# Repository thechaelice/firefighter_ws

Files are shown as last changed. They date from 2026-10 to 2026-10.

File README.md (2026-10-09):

# Autonomous Firefighter Robot (`firefighter_ws`)

An autonomous firefighting robotic system designed for rapid fire detection, navigation, localization, and suppression. The system integrates low-power wireless alert beacons with an autonomous mobile robot equipped with LiDAR SLAM, laser odometry, thermal vision, and a targeted fire retardant delivery system.

---

## Architecture Overview

```mermaid
flowchart TD
    subgraph Beacon [Fire Beacon - ESP32]
        B1[Fire / Smoke Sensor] --> B2[ESP32 Controller]
        B2 -->|ESP-NOW Wireless Alert| R2
    end

    subgraph Robot [Mobile Firefighter Robot]
        subgraph ESP32_Robot [Mobility Controller - ESP32]
            R2[ESP-NOW Receiver] --> R3[Motor Drivers & Locomotion]
        end

        subgraph Pi_Robot [Processing & Perception - Raspberry Pi]
            Lidar[RPLiDAR Sensor] -->|Serial| ROS_Scan[ROS 2: sllidar_ros2]
            ROS_Scan -->|/scan| ROS_Odom[ROS 2: rf2o_laser_odometry]
            ROS_Odom -->|/odom_rf2o + TF| SLAM[SLAM & Navigation Stack]
            Thermal[Thermal Camera - MLX90641 16x12] --> ML[Flame Localization & ML - In development]
            Extinguisher[Fire Retardant Dispenser - Planned]
        end

        Pi_Robot <-->|UART / ROS-Serial| ESP32_Robot
    end
```

### 1. Smart Fire Beacon (ESP32)
* **Function**: Acts as a remote smoke / heat detector placed in monitored rooms.
* **Communication**: Transmits low-latency, low-power alert signals to the robot over **ESP-NOW** when fire or smoke is detected.

### 2. Autonomous Mobile Robot
The robot is built with a dual-controller architecture:
* **Raspberry Pi (High-Level Computing & Perception)**:
  * Runs ROS 2 (Jazzy) for sensor processing, LiDAR SLAM, mapping, path planning, and ML workloads.
  * Interfaces with the LiDAR for real-time laser odometry and 2D environmental mapping.
  * Thermal imaging with a **Melexis MLX90641** (16 × 12 = 192-pixel) IR array on
    I²C (`0x33`) to pinpoint the base of the flame — driver verified, perception in
    development (see [`docs/thermal-camera.md`](docs/thermal-camera.md)).
* **ESP32 (Mobility & Hardware Control)**:
  * Handles low-level motor drivers, wheel velocity control, and wheel odometry.
  * Maintains the ESP-NOW communication link with fire alert beacons.

---

## System Operational Workflow

1. **Detection & Alert**: An ESP32 beacon senses smoke/fire and dispatches a beacon alert packet via ESP-NOW.
2. **Dispatch & Navigation**: The robot receives the alert and uses LiDAR-based SLAM and odometry (`rf2o_laser_odometry`) to navigate autonomously to the reported room.
3. **Flame Localization**: Once in proximity, the onboard **MLX90641** thermal camera (16 × 12 IR array) scans the area to pinpoint the exact fire source.
4. **Fire Suppression**: The robot positions itself and activates the fire retardant dispensing mechanism to extinguish the flames.

---

## Current Repository Status

| Component | Hardware / Software | Status | Description |
|---|---|---|---|
| **LiDAR Driver** | RPLiDAR + `sllidar_ros2` | ✅ Implemented | Reads LiDAR data and publishes `/scan` topic |
| **Laser Odometry** | `rf2o_laser_odometry` | ✅ Implemented | Computes planar odometry (`/odom_rf2o`, `odom → base_link` TF) |
| **Live LiDAR Terminal Viewer** | `scripts/ascii_lidar_view.py` | ✅ Implemented | Headless polar ASCII radar visualizer for `/scan` |
| **Operations Dashboard** | `scripts/robot_dashboard.py` | ✅ Implemented | One web page: LiDAR 2D/3D, optional SLAM map and thermal camera feeds, beacon alerts + RSSI, ESP32 link/mode/e-stop, mission state, odometry, per-topic rates, event log |
| **Motor Bench Test** | `scripts/motor_test.py` | ✅ Implemented | Drives the motors from the Pi via `/cmd_vel` (scripted or keyboard) with `/wheel_odom` feedback |
| **Thermal Frame Capture/Render** | `scripts/thermal_frames.py` + `scripts/thermal/` | ✅ Implemented | Captures Melexis **MLX90641** frames and renders PNG heat maps (see [`docs/thermal-camera.md`](docs/thermal-camera.md)) |
| **Pi ↔ ESP32 Serial Bridge** | `firefighter_bridge` (ament_python) | ✅ Implemented | Framed UART link: `/cmd_vel` → `SET_TWIST`, wheel odom, beacon events (see [`src/firefighter_bridge/`](src/firefighter_bridge/README.md)) |
| **Mission Behaviour FSM** | `firefighter_mission` (ament_python) | ✅ Implemented | `beacon → navigate → search → suppress → verify` state machine, e-stop, bounded timeouts (see [`src/firefighter_mission/`](src/firefighter_mission/README.md)) |
| **ESP-NOW Fire Beacon** | ESP32 + Flame/Smoke Sensors | ✅ Implemented | HL-01 flame + MQ-2 smoke sensing with detection latching, non-blocking 2 s ESP-NOW alert transmission (see [`firmware/`](firmware/README.md)) |
| **Robot Mobility Controller** | ESP32 + Motor Drivers | ✅ In Firmware | Motor control firmware and ESP-NOW receiver (see [`firmware/`](firmware/README.md)) |
| **SLAM & Path Planning** | `slam_toolbox` + Nav2 + `robot_localization` | ✅ Implemented | Mapping, EKF fusion (`/odom_rf2o` + `/wheel_odom`) and Nav2 path planning (see [`src/firefighter_bringup/`](src/firefighter_bringup/README.md)) |
| **Thermal Flame Localization**| Melexis **MLX90641** (16 × 12) + ML model | ✅ Implemented | 16×12 IR array → thermal image + bearing/range to the flame (see [`src/firefighter_perception/`](src/firefighter_perception/README.md)); ML model still pending |
| **Fire Retardant Dispenser** | Actuator / Pump / Nozzle | ⏳ Planned | Automated fire suppression dispenser |

### Upstream ROS 2 Packages

The following packages are included in `src/`:

* [`sllidar_ros2`](src/sllidar_ros2/) from [Slamtec/sllidar_ros2](https://github.com/Slamtec/sllidar_ros2)
* [`rf2o_laser_odometry`](src/rf2o_laser_odometry/) from [MAPIRlab/rf2o_laser_odometry](https://github.com/MAPIRlab/rf2o_laser_odometry)

---

## Getting Started (ROS 2 Workspace)

### 1. Build the Workspace

Ensure ROS 2 (Jazzy) is installed and sourced. For a from-scratch install - the
Pi, or Gazebo simulation on a PC under WSL2 - follow [`setup.md`](setup.md).

> [!WARNING]
> On this Raspberry Pi 4, do **not** run a bare `colcon build --symlink-install`.
> colcon runs each package as `cmake --build ... -- -j4 -l4` and builds packages
> in parallel, i.e. up to 8 concurrent `g++` jobs on a 4-core board with 3.7 GB
> RAM and **no swap**, while the VS Code remote server is resident. That drives
> the system into memory pressure, whose writeback wedges the SD/MMC controller
> (`mmc_rescan` blocked >120 s). Since the root filesystem *and* the Wi-Fi radio
> both hang off that MMC/SDIO bus, the Pi loses disk I/O and networking at the
> same time — SSH drops and can't reconnect, and only a power cycle recovers it.

Use the wrapper instead, which caps compiler parallelism and builds one package
at a time:

```bash
cd ~/firefighter_ws
./build.sh
```

Equivalent to running the following by hand:

```bash
cd ~/firefighter_ws
source /opt/ros/jazzy/setup.bash
MAKEFLAGS="-j1 -l1" colcon build --symlink-install --executor sequential
source install/setup.bash
```

`install/setup.bash` only appears once a build finishes successfully — if
`sourcing install/setup.bash` fails, the previous build did not complete.

#### Recommended Pi hardening (prevents the lockups entirely)

The build wrapper avoids *triggering* the fault; these steps make the board
robust if it happens for another reason:

```bash
# 1. zram swap: compressed swap in RAM, so memory pressure never turns into
#    SD-card writeback. Cheap and safe on a Pi.
sudo apt install zram-tools
#    then set ALGO=zstd and PERCENT=50 in /etc/default/zramswap and
#    sudo systemctl restart zramswap

# 2. earlyoom: kills the biggest memory hog before the box wedges, instead of
#    hanging until the MMC controller gives up.
sudo apt install earlyoom
```

Also worth doing:

- **Put the root filesystem on a USB SSD** (or at least a better SD card). This
  unit's card reports as a generic `SD32G` in DDR50 mode, and cheap cards stall
  under sustained writeback — the actual trigger here.
- **Disable Wi-Fi power save** (`iw dev wlan0 set power_save off`, or the
  NetworkManager `wifi.powersave 2` setting) or, better, **use Ethernet**. SSH
  currently runs over a Wi-Fi hotspot, and the radio shares the MMC/SDIO bus
  with the SD card, so a storage stall also kills the network link.

---

### 2. Launch the LiDAR Driver

```bash
ros2 launch sllidar_ros2 sllidar_a1_launch.py serial_port:=/dev/ttyUSB0
```

### 3. Launch Laser Odometry

```bash
ros2 launch rf2o_laser_odometry rf2o_laser_odometry.launch.py
```

### 4. Optional: Terminal ASCII LiDAR Visualizer

For headless debugging over SSH:

```bash
python3 scripts/ascii_lidar_view.py
```

### 5. Optional: Operations Dashboard (browser)

`scripts/robot_dashboard.py` serves a single page with everything the robot is
doing: the live LiDAR scan (2D and optional 3D), beacon alerts with RSSI and an
estimated range, the mobility ESP32's link/mode/e-stop state, the mission FSM
state and suppression, wheel vs laser odometry, a per-topic rate and freshness
table, and a rolling event log.

```bash
cd ~/firefighter_ws && source install/setup.bash
python3 scripts/robot_dashboard.py
```

Open `http://<pi-ip>:8080/` from a browser on the same network. The 3D view can
display a `PointCloud2` topic when configured:

```bash
python3 scripts/robot_dashboard.py --pointcloud-topic /points
```

The RPLIDAR publishes planar `LaserScan` data, so without a `PointCloud2` topic
the 3D view shows the scan as a flat plane. The server has no authentication and
binds to all interfaces; use it only on a trusted network.

### 6. Optional: Drive the Motors (bench test)

`scripts/motor_test.py` is a bring-up tool for the drive train. It publishes
`/cmd_vel`, which `firefighter_bridge` streams to the ESP32 as `SET_TWIST`, and
reports `/wheel_odom` back so you can see the wheels turning.

```bash
cd ~/firefighter_ws && source install/setup.bash

# creep forward for 2 s, then stop
python3 scripts/motor_test.py --linear 0.10 --duration 2

# spin in place
python3 scripts/motor_test.py --angular 0.5 --duration 3

# keyboard driving: w/s = speed, a/d = turn, space = stop, q = quit
python3 scripts/motor_test.py --interactive
```

> **Stop `firefighter_mission` first.** It also publishes `/cmd_vel`, so the two
> will fight over the motors.

Put the robot on blocks for the first run. Zero is published on every exit path,
and killing the script stops the robot anyway (the bridge zeros stale commands
after `cmd_timeout_s`, and the ESP32 stops itself after `PI_TIMEOUT_MS`).
Add `--estop` to latch a stop on the ESP32 when the test finishes.

For detailed setup, troubleshooting, and port configuration, refer to [`docs/runbook.md`](docs/runbook.md).

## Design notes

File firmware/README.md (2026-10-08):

# ESP32 Firmware Documentation

This directory contains the embedded firmware for the Firefighter Robot system, split into two ESP32 microcontrollers communicating wirelessly via **ESP-NOW**.

---

## Directory Layout

```text
firmware/
├── beacon/
│   └── beacon.ino             # Fire & smoke detector beacon sketch (Sender)
├── robot_mobility/
│   └── robot_mobility.ino     # Robot motor driver & ESP-NOW receiver sketch
└── README.md                  # Firmware guide, pinouts, and flashing instructions
```

---

## System Architecture

```mermaid
flowchart LR
    subgraph Beacon [Fire Beacon - ESP32]
        Sensor[Flame / Smoke Sensor] --> BeaconESP[ESP32 Sender]
        BeaconESP -->|ESP-NOW Broadcast / Unicast| RecvESP
    end

    subgraph Robot [Robot Mobility - ESP32]
        RecvESP[ESP32 Receiver] --> Drivers[L298N / Motor Driver]
        Drivers --> M1[Motor 1 (Left)]
        Drivers --> M2[Motor 2 (Right)]
        Encoders[Quadrature Encoders] -.-> RecvESP
    end
```

---

## 1. Wireless Protocol (ESP-NOW)

The beacon and the robot communicate using **ESP-NOW**, a low-latency, low-power peer-to-peer 2.4 GHz wireless protocol developed by Espressif.

### Packet Structure
Both sender (`beacon.ino`) and receiver (`robot_mobility.ino`) must share the exact same message struct:

```cpp
typedef struct struct_message {
    int messageNumber;
    bool fireDetected;
    bool smokeDetected;
} struct_message;
```

### Pairing & MAC Address Setup
Pairing is automatic; no MAC address is hardcoded.

1. The beacon broadcasts a `PAIR_REQUEST` every 500 ms until it has a receiver.
2. The mobility ESP32 answers with a broadcast `PAIR_REPLY`.
3. The beacon takes the receiver MAC from the source address of that reply, registers it as its ESP-NOW peer and starts sending alert packets to it (`Receiver found: XX:XX:XX:XX:XX:XX` on the beacon's Serial Monitor).
4. After 5 consecutive undelivered packets the beacon forgets the receiver and goes back to step 1, so a swapped or rebooted mobility ESP32 is picked up without reflashing.

Both sketches must be flashed with matching `pair_message` definitions. The beacon pairs with the first mobility ESP32 that answers, so only one should be powered within range.

### Signal Strength (RSSI) & Distance Estimation
* **Interim (Active)**: The mobility ESP32 captures the received packet signal strength (RSSI in dBm) via a promiscuous Wi-Fi hook (Core 2.0.x) or `esp_now_recv_info_t` (Core 3.0.x) and forwards it in `MSG_BEACON_EVENT` to ROS 2 topic `/beacon_event`.
  * Typical indoor Wi-Fi path-loss formula: $\text{RSSI} \approx \text{RSSI}_0 - 10 n \log_{10}(d)$.
  * Provides coarse proximity indication (e.g. Strong: $-40\text{ to }-55\text{ dBm} \rightarrow <2\text{m}$, Moderate: $-60\text{ to }-75\text{ dBm} \rightarrow 2\text{--}6\text{m}$, Weak: $<-80\text{ dBm} \rightarrow >6\text{m}$).
* **Target Upgrade (UWB Ranging)**: Ultra-Wideband Two-Way Ranging (DWM1000/DWM3000) for high-precision $\pm 5\text{--}10\text{ cm}$ indoor ranging. See the [UWB Migration Guide](../docs/uwb-ranging-migration.md).

---

## 2. Hardware Pinout & Wiring

### Robot Mobility Controller (`robot_mobility.ino`)

#### Motor Driver (e.g. L298N / Dual H-Bridge)
| Signal | ESP32 GPIO | Description |
|---|---|---|
| **ENA** | GPIO 14 | Motor 1 Speed (PWM Channel 0) |
| **IN1** | GPIO 27 | Motor 1 Direction A |
| **IN2** | GPIO 26 | Motor 1 Direction B |
| **IN3** | GPIO 25 | Motor 2 Direction A |
| **IN4** | GPIO 33 | Motor 2 Direction B |
| **ENB** | GPIO 32 | Motor 2 Speed (PWM Channel 1) |

#### Optical / Magnetic Encoders
| Encoder | Channel A (Green) | Channel B (Blue) | Description |
|---|---|---|---|
| **Motor 1** | GPIO 18 | GPIO 19 | Left wheel quadrature encoder |
| **Motor 2** | GPIO 22 | GPIO 23 | Right wheel quadrature encoder |

#### PWM Configuration
* **Frequency**: 5 kHz
* **Resolution**: 8-bit (values `0` – `255`)
* **Default Speed**: `180` (~71% duty cycle), used only by the fallback maneuver

#### Closed-Loop Wheel Speed Control
In Pi-owned mode each `SET_TWIST` becomes a per-wheel speed target, and a 50 Hz
feedforward + PI loop on the encoder speed drives the PWM, so slow commands
(search spin, flame approach, Nav2 fine positioning) are actually achieved.

* **Geometry**: `WHEEL_RADIUS_M` and `ENCODER_TICKS_PER_REV` in the sketch must match `wheel_radius_m` / `ticks_per_rev` in the bridge's `config/bridge.yaml`.
* **Encoder direction**: each encoder must count **up** when its wheel drives the robot forward; flip `M1_ENC_INVERT` / `M2_ENC_INVERT` if not.
* **Encoder fault**: if a wheel's encoder counts opposite to its motor, or gives no counts while driven hard, for 0.7 s, both wheels drop back to open-loop feedforward until `MSG_RESET_FAULT`. It is reported to the Pi as `FLAG_ENC_FAULT` (bit 4) in `MSG_STATUS`, which the bridge raises as an ERROR on `/diagnostics`, and printed as `[vel] ENCODER FAULT` on the debug serial.
* **Tuning**: `VEL_KP`, `VEL_KI` and `MOTOR_MIN_MOVE_PWM` are untuned starting values. `VELOCITY_CONTROL_ENABLED 0` restores open-loop.
* A zero target stops the motors immediately; the loop never reverses a motor to brake.

---

## 3. Behavior & Trigger Logic

> **Note:** the legacy trigger/maneuver described here now runs **only as a fallback**
> (`MOTION_OWNER_IS_PI 0`). By default the Pi owns motion — see [§5](#5-pi--esp32-uart-link-option-a--active).

### Trigger Condition
* The robot requires **2 consecutive packets** with both `fireDetected == true` and `smokeDetected == true` before triggering movement to prevent false positives.
* If a packet arrives without both conditions satisfied, the consecutive counter resets to 0.

### Maneuver Sequence
When triggered, the robot executes the following fixed sequence:
1. **Forward**: 5 seconds
2. **Stop**: 0.5 seconds
3. **Turn Right**: 3 seconds
4. **Stop**: 0.5 seconds
5. **Turn Left**: 5 seconds
6. **Final Stop**: Shuts down motors, clears old flags, and resumes listening for new alert packets.

*Note: During execution of the sequence, all incoming ESP-NOW commands are safely ignored.*

---

## 4. Flashing & Setup Instructions

### Prerequisites
* **Arduino IDE** (v1.8.x or v2.x) or **VS Code with PlatformIO / Arduino extension**
* **ESP32 Board Package**: `esp32` by Espressif Systems (Core 2.0.x recommended)

### Board Settings in Arduino IDE
* **Board**: `ESP32 Dev Module` (or your specific ESP32 board)
* **CPU Frequency**: `240MHz (WiFi/BT)`
* **Flash Frequency**: `80MHz`
* **Upload Speed**: `921600` (or `115200` if flashing fails)
* **Baud Rate**: `115200`

---

## 5. Pi ↔ ESP32 UART Link (Option A — active)

The mobility ESP32 is now a **gateway**: it keeps the ESP-NOW link to the beacon and
bridges everything to the Raspberry Pi over a framed binary UART protocol.

```
Beacon --ESP-NOW--> [Mobility ESP32] --UART2--> Raspberry Pi (ROS 2)
```

### Wiring
| Pi | ESP32 | Note |
|---|---|---|
| GPIO14 (TXD) | GPIO16 (RX) | UART2, 115200 8N1 |
| GPIO15 (RXD) | GPIO17 (TX) | do **not** use UART1 (GPIO9/10 — flash pins) |
| GND | GND | required |

Both sides are 3.3 V — no level shifter. The Pi must expose a UART on GPIO14/15
(see [`docs/runbook.md`](../docs/runbook.md): `dtoverlay=miniuart-bt` and remove the serial console).

### Protocol
Defined once in [`robot_mobility/firefighter_protocol.h`](robot_mobility/firefighter_protocol.h).
Frame: `A5 5A | LEN | MSG_ID | PAYLOAD | CRC16-LE` (CRC-16/CCITT-FALSE over LEN..payload).

| Pi → ESP32 | | ESP32 → Pi | |
|---|---|---|---|
| `SET_TWIST` `0x01` | f32 lin, ang | `WHEEL_ODOM` `0x81` | i32 ticksL/R, u32 dt_us |
| `ESTOP` `0x02` | — | `STATUS` `0x82` | u16 vbat, u8 flags, u8 mode |
| `RESET_FAULT` `0x03` | — | `BEACON_EVENT` `0x83` | u32 msg, fire, smoke, rssi, mac |
| `HEARTBEAT` `0x04` | u16 seq | `ACK` `0x84` / `HB_ESP` `0x85` | |

### Motion ownership
Set by `MOTION_OWNER_IS_PI` at the top of `robot_mobility.ino`:

* **`1` (default)** — the Pi owns motion: it streams `SET_TWIST`, and beacon events are
  only *forwarded* so the Pi's autonomy stack decides what to do.
* **`0`** — fallback: the ESP32 runs its original fixed forward/right/left maneuver on
  two consecutive beacon FIRE + SMOKE detections (still non-blocking).

### Safety
* **Watchdog** — in Pi mode, no valid frame for `PI_TIMEOUT_MS` (500 ms) → motors stop.
* **E-stop** — `ESTOP` latches a stop until `RESET_FAULT` arrives.
* The whole control path is `millis()`-based; the legacy blocking `delay()` maneuver
  is preserved as `robot_mobility.blocking.bak` for reference.

---

## 6. Option B — micro-ROS (deferred)

An alternative where the ESP32 becomes a native ROS 2 node via `micro_ros_agent`,
removing the custom protocol. Kept on the shelf, not built.
See [`docs/option-b-micro-ros.md`](../docs/option-b-micro-ros.md).

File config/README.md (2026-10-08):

# config/

Parameter files for **upstream packages whose source we don't own**. Keeping them
here rather than inside `src/` means a workspace rebuild can never overwrite tuned
values, and `firefighter_bringup` loads them by absolute path.

| File | Package | Status |
|---|---|---|
| `rf2o.yaml` | `rf2o_laser_odometry` | adapted — `publish_tf: false` (the EKF owns `odom → base_link`) |
| `ekf.yaml` | `robot_localization` | purpose-written — fuses `/odom_rf2o` + `/wheel_odom` |
| `slam_toolbox.yaml` | `slam_toolbox` | stock defaults, `base_frame` → `base_link`. **Not tuned** |
| `nav2_params.yaml` | `nav2_bringup` | stock defaults, frames/odom/radius adapted. **Not tuned** |

## Provenance

`slam_toolbox.yaml` and `nav2_params.yaml` are copies of the shipped Jazzy configs:

* `/opt/ros/jazzy/share/slam_toolbox/config/mapper_params_online_async.yaml`
* `/opt/ros/jazzy/share/nav2_bringup/params/nav2_params.yaml`

Only frames, the odometry source and the robot radius were changed; each file has a
header comment listing exactly what differs. **Nothing has been validated on real
hardware** — a stock Nav2 config is a starting point, not a tuned one. Speeds,
acceleration limits, inflation radii and the progress checker all need revisiting
once the robot drives. `robot_radius: 0.18` in particular is a placeholder.

`ekf.yaml` and `rf2o.yaml` were written for this robot rather than copied.

Package-owned parameters live with their package (e.g.
`src/firefighter_bridge/config/bridge.yaml`).

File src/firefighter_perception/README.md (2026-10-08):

# firefighter_perception

Thermal flame perception from the **Melexis MLX90641** 16×12 IR array.

```
MLX90641 (I2C 0x33) ──> scripts/thermal/mlx90641_frames ──> thermal_node ──┬──> /thermal/image       (32FC1)
                              (vendored C reader)                          ├──> /thermal/camera_info
                                                                           └──> /flame_event
                                                                                   ▲
/scan ────────────────────────────────────────────────────────────────────────────┘
```

There is no MLX90641 driver on PyPI (see `docs/thermal-camera.md`), so frames come
from the vendored C tool via `thermal_reader.py`, which runs it in a background
thread and restarts it if it dies. This package needs **no numpy**.

## The array gives a bearing, not a range

A 16×12 array on a fixed-FOV lens tells you *where* the hot spot is, not how far
away it is. Range comes from the LiDAR: `scan_range_at_bearing()` looks up the
`/scan` return at the flame's bearing (median of the returns in a ±6° window, so one
spurious point cannot decide it). That also settles `IN_SUPPRESSION_RANGE`.

## What it publishes, and what it deliberately does not

| State | Meaning |
|---|---|
| `FLAME_FOUND` | a hot spot is present |
| `IN_SUPPRESSION_RANGE` | ...and the LiDAR says it is within `suppression_range_m` |
| `FLAME_LOST` | nothing hot in view |

It never publishes `FLAME_EXTINGUISHED`. Deciding that "gone" means "it went out"
needs to know that you had been suppressing — that is the mission's job, and
`firefighter_mission` maps `FLAME_LOST` → extinguished while suppressing/verifying.

## Topics

| Name | Type | Dir |
|---|---|---|
| `/thermal/image` | `sensor_msgs/Image` (32FC1, degrees C) | out |
| `/thermal/camera_info` | `sensor_msgs/CameraInfo` | out |
| `/flame_event` | `firefighter_interfaces/FlameEvent` | out |
| `/scan` | `sensor_msgs/LaserScan` | in |

## Run

```bash
cd ~/firefighter_ws && ./build.sh && source install/setup.bash
ros2 launch firefighter_perception perception.launch.py
```

`reader_path` defaults to `$FIREFIGHTER_WS/scripts/thermal/mlx90641_frames`
(override with `reader_path:=`). Build the reader first with
`bash scripts/thermal/build.sh`.

## Tuning

`config/perception.yaml`. The thresholds are `min(threshold_c, ambient + delta_c)`,
so a warm room where nothing reaches 60 °C still triggers on a 20 °C rise. Note the
sensor delivers roughly **2 Hz**, not the 5 Hz the acquisition setting suggests —
the MLX90641's subpage reads dominate. Images are published one per *new* frame, not
at the timer rate, so a dead reader cannot keep reporting a stale `FLAME_FOUND`.

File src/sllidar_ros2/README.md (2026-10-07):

# SLAMTEC LIDAR ROS2 Package

ROS2 node for SLAMTEC LIDAR

Visit following Website for more details about SLAMTEC LIDAR:

SLAMTEC LIDAR roswiki: <http://wiki.ros.org/rplidar>

SLAMTEC LIDAR HomePage: <http://www.slamtec.com/en/Lidar>

SLAMTEC LIDAR SDK: <https://github.com/Slamtec/rplidar_sdk>

SLAMTEC LIDAR Tutorial: <https://github.com/robopeak/rplidar_ros/wiki>

## Supported SLAMTEC LIDAR

| Lidar Model |
| ---------------------- |
|RPLIDAR A1              |
|RPLIDAR A2              |
|RPLIDAR A3              |
|RPLIDAR C1              |
|RPLIDAR S1              |
|RPLIDAR S2              |
|RPLIDAR S3              |
|RPLIDAR S2E             |
|RPLIDAR T1              |

## How to install ROS2

[rolling](https://docs.ros.org/en/rolling/Installation.html),
[humble](https://docs.ros.org/en/humble/Installation.html),
[galactic](https://docs.ros.org/en/galactic/Installation.html),
[foxy](https://docs.ros.org/en/foxy/Installation.html)

## How to configuring your ROS 2 environment

[Configuring your ROS 2 environment](https://docs.ros.org/en/foxy/Tutorials/Configuring-ROS2-Environment.html)

## How to Create a ROS2 workspace

[ROS2 Tutorials Creating a workspace](https://docs.ros.org/en/foxy/Tutorials/Workspace/Creating-A-Workspace.html)

1. example, choose the directory name firefighter_ws, for "development workspace" :

   ```bash
   mkdir -p ~/firefighter_ws/src
   cd ~/firefighter_ws/src
   ```

## Compile & Install sllidar_ros2 package

1. Clone sllidar_ros2 package from github

   Ensure you're still in the firefighter_ws/src directory before you clone:

   ```bash
   git clone https://github.com/Slamtec/sllidar_ros2.git
   ``` 

2. Build sllidar_ros2 package

   From the root of your workspace (firefighter_ws), you can now build sllidar_ros2 package using the command:

   ```bash
   cd ~/firefighter_ws/
   source /opt/ros/<rosdistro>/setup.bash
   colcon build --symlink-install
   ```

   if you find output like "colcon:command not found",you need separate [install colcon](https://docs.ros.org/en/foxy/Tutorials/Colcon-Tutorial.html#install-colcon) build tools.

3. Package environment setup

    ```bash
    source ./install/setup.bash
    ```

    Note: Add permanent workspace environment variables.
    It's convenientif the ROS2 environment variables are automatically added to your bash session every time a new shell is launched:

    ```bash
    $echo "source <your_own_firefighter_ws>/install/setup.bash" >> ~/.bashrc
    $source ~/.bashrc
    ```

4. Create udev rules for rplidar

   sllidar_ros2 running requires the read and write permissions of the serial device.
   You can manually modify it with the following command:

   ```bash
   sudo chmod 777 /dev/ttyUSB0
   ```

   But a better way is to create a udev rule:

   ```bash
   cd src/rpldiar_ros/
   source scripts/create_udev_rules.sh
   ```

## Run sllidar_ros2

### Run sllidar node and view in the rviz

The command for RPLIDAR A1 is :

```bash
ros2 launch sllidar_ros2 view_sllidar_a1_launch.py
```

The command for RPLIDAR A2M7 is :

```bash
ros2 launch sllidar_ros2 view_sllidar_a2m7_launch.py
```

The command for RPLIDAR A2M8 is :

```bash
ros2 launch sllidar_ros2 view_sllidar_a2m8_launch.py
```

The command for RPLIDAR A2M12 is :

```bash
ros2 launch sllidar_ros2 view_sllidar_a2m12_launch.py
```

The command for RPLIDAR A3 is :

```bash
ros2 launch sllidar_ros2 view_sllidar_a3_launch.py
```

The command for RPLIDAR C1 is :

```bash
ros2 launch sllidar_ros2 view_sllidar_c1_launch.py
```

The command for RPLIDAR S1 is :

```bash
ros2 launch sllidar_ros2 view_sllidar_s1_launch.py
```

The command for RPLIDAR S2 is :

```bash
ros2 launch sllidar_ros2 view_sllidar_s2_launch.py
```

```bash
ros2 launch sllidar_ros2 view_sllidar_s2e_launch.py
```

The command for RPLIDAR S3 is :

```bash
ros2 launch sllidar_ros2 view_sllidar_s3_launch.py
```

The command for RPLIDAR T1 is :

```bash
ros2 launch sllidar_ros2 view_sllidar_t1_launch.py
```

The command for RPLIDAR S1(TCP connection) is :

```bash
ros2 launch sllidar_ros2 view_sllidar_s1_tcp_launch.py
```

Notice: different lidar use different serial_baudrate.

## RPLIDAR frame

RPLIDAR frame must be broadcasted according to picture shown in rplidar-frame.png

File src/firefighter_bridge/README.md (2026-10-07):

# firefighter_bridge

UART bridge between the **mobility ESP32** and the ROS 2 graph.

```
/cmd_vel  --SET_TWIST-->  [ESP32]  --WHEEL_ODOM-->  /wheel_odom  (nav_msgs/Odometry)
/beacon_event  <--BEACON_EVENT-- [ESP32] <--ESP-NOW-- beacon
                                   --STATUS-->      /battery, /diagnostics
```

The wire format is defined once in `firefighter_protocol.h` (ESP32) and
`firefighter_bridge/protocol.py` (Pi). The golden-frame tests in
`tests/test_protocol_codec.py` keep the two in lock-step.

## Run

```bash
cd ~/firefighter_ws && ./build.sh          # or: colcon build --packages-select firefighter_interfaces firefighter_bridge
source install/setup.bash
ros2 launch firefighter_bridge bridge.launch.py port:=/dev/ttyAMA0
```

See `docs/runbook.md` for enabling the PL011 UART on GPIO14/15.

## Topics & services

| Name | Type | Dir | Notes |
|---|---|---|---|
| `/cmd_vel` | `geometry_msgs/Twist` | in | streamed as `SET_TWIST` at `cmd_rate_hz` |
| `/wheel_odom` | `nav_msgs/Odometry` | out | integrated from encoder ticks |
| `/beacon_event` | `firefighter_interfaces/BeaconEvent` | out | forwarded beacon alerts |
| `/battery` | `sensor_msgs/BatteryState` | out | voltage is `NaN` until a battery ADC exists |
| `/diagnostics` | `diagnostic_msgs/DiagnosticArray` | out | ESP32 mode / flags / link health |
| `~/estop` | `std_srvs/Trigger` | srv | latches `ESTOP` |
| `~/clear_fault` | `std_srvs/Trigger` | srv | sends `RESET_FAULT` |

## Why `/wheel_odom` and not `/odom`

`rf2o_laser_odometry` already broadcasts `odom -> base_link`. A second publisher
of the same transform makes the TF tree ambiguous, so the bridge publishes to
`/wheel_odom` and leaves `publish_tf` off. A `robot_localization` EKF can later
fuse `/odom_rf2o` + `/wheel_odom` and take over the TF.

## Safety

* The node streams `SET_TWIST` every cycle (zero when idle), which keeps the
  ESP32 watchdog fed. If the node dies, the frames stop and the ESP32 stops
  the motors itself after `PI_TIMEOUT_MS` (500 ms).
* `/cmd_vel` older than `cmd_timeout_s` is treated as zero.

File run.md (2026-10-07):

# Running the LiDAR Odometry Workspace

ROS 2 workspace (`~/firefighter_ws`) with two packages:

- **`sllidar_ros2`** — SLAMTEC RPLIDAR driver. Reads the LiDAR over serial and publishes `sensor_msgs/LaserScan` on `/scan`.
- **`rf2o_laser_odometry`** — RF2O planar laser odometry. Subscribes to `/scan`, publishes `nav_msgs/Odometry` on `/odom_rf2o` and broadcasts TF `odom → base_link`.

```mermaid
flowchart LR
    A[RPLIDAR] -->|serial| B[sllidar_node]
    B -->|/scan| C[rf2o_laser_odometry_node]
    C -->|/odom_rf2o + TF| D[odometry]
```

---

## 1. Build

> **Do not run a bare `colcon build --symlink-install` on this Pi 4.**
> colcon invokes each package as `cmake --build ... -- -j4 -l4` and builds both
> packages concurrently — up to 8 `g++` jobs on a 4-core board with 3.7 GB RAM
> and no swap. The resulting memory pressure wedges the SD/MMC controller, and
> because the root filesystem *and* the Wi-Fi radio share the MMC/SDIO bus, the
> Pi simultaneously loses disk I/O and networking. SSH drops, cannot reconnect,
> and the board must be power-cycled.

Prefer the wrapper, which caps the build to one compiler job and one package at
a time:

```bash
cd ~/firefighter_ws
./build.sh
```

The underlying command it runs:

```bash
cd ~/firefighter_ws
source /opt/ros/jazzy/setup.bash
MAKEFLAGS="-j1 -l1" colcon build --symlink-install --executor sequential
source install/setup.bash
```

`JOBS=2 ./build.sh` is usually still safe if the Pi is otherwise idle.

See [README → Build the Workspace](README.md#1-build-the-workspace) for the
hardening steps (zram swap, `earlyoom`, USB-SSD root) that make builds robust.

---

## 2. Find the LiDAR port

```bash
ls -l /dev/ttyUSB* /dev/ttyACM* /dev/serial/by-id/ 2>/dev/null
```

| Wiring | Port |
|---|---|
| USB adapter (typical RPLIDAR dongle) | `/dev/ttyUSB0` |
| Direct to GPIO pins 8 (TXD) / 10 (RXD) | `/dev/ttyS0` |

Prefer the stable by-id path so the number doesn't change:

```bash
ls -l /dev/serial/by-id/
```

---

## 3. Permissions (if needed)

```bash
sudo chmod 777 /dev/ttyUSB0
```

---

## 4. Run the LiDAR driver

```bash
cd ~/firefighter_ws && source install/setup.bash
ros2 launch sllidar_ros2 sllidar_a1_launch.py serial_port:=/dev/ttyUSB0
```

Use the launch file that matches your model (e.g. `sllidar_a2m8_launch.py`, `sllidar_s1_launch.py`, …). Note different models use different `serial_baudrate`.

### Start the motor (if no scan appears)

The A1 motor doesn't always auto-start. If `/scan` stays silent:

```bash
ros2 service call /start_motor std_srvs/srv/Empty "{}"
```

### Verify data is flowing

```bash
ros2 topic hz /scan          # should show ~7–10 Hz
ros2 topic echo /scan --once # should print a LaserScan message
```

---

## 5. Run the odometry

```bash
cd ~/firefighter_ws && source install/setup.bash
ros2 launch rf2o_laser_odometry rf2o_laser_odometry.launch.py
```

The node looks up the transform `base_link → laser`, so add a static transform for the LiDAR's physical offset on the robot (zero here; adjust to your mount):

```bash
ros2 run tf2_ros static_transform_publisher 0 0 0 0 0 0 base_link laser
```

Defaults: reads `/scan`, publishes `/odom_rf2o`, TF `odom → base_link`.

---

## 6. Viewing the data

### Foxglove Studio (recommended, works headless over SSH)

```bash
source /opt/ros/jazzy/setup.bash
ros2 launch foxglove_bridge foxglove_bridge_launch.xml port:=8765
```

Then open <https://studio.foxglove.dev/> in a browser, connect to `ws://<pi-ip>:8765`, and add a **3D** panel with topic `/scan` (frame `laser`).

### ASCII radar view (terminal, no display needed)

```bash
cd ~/firefighter_ws && source install/setup.bash && python3 ascii_lidar_view.py
```

### Tweakable parameters

```bash
python3 ascii_lidar_view.py --ros-args \
  -p scan_topic:=/scan \
  -p max_range:=10.0 \
  -p size:=61 \
  -p rate:=15.0
```

| Param | Default | Meaning |
|---|---|---|
| `scan_topic` | `/scan` | LaserScan topic to read |
| `max_range` | `6.0` | View radius in meters |
| `size` | `41` | Grid width/height in characters |
| `rate` | `10.0` | Refresh rate (Hz) |

### RViz2 (needs a display)

```bash
rviz2 -d $(ros2 pkg prefix sllidar_ros2)/share/sllidar_ros2/rviz/sllidar_ros2.rviz
```

---

## Troubleshooting

- **`colcon: command not found`** — `sudo apt install python3-colcon-common-extensions`
- **No `/dev/ttyUSB*`** — check the USB cable/power; `lsusb` should show a `CP210x` / `CH340` / `FTDI` device.
- **Node runs but no scan** — call `/start_motor` (see §4).
- **Scan freezes after a while** — the motor has stalled; call `/start_motor` again, or power the LiDAR from a powered USB hub.

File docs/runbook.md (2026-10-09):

# Running the LiDAR Odometry Workspace

ROS 2 workspace (`~/firefighter_ws`) with two packages:

- **`sllidar_ros2`** — SLAMTEC RPLIDAR driver. Reads the LiDAR over serial and publishes `sensor_msgs/LaserScan` on `/scan`.
- **`rf2o_laser_odometry`** — RF2O planar laser odometry. Subscribes to `/scan`, publishes `nav_msgs/Odometry` on `/odom_rf2o` and broadcasts TF `odom → base_link`.

```mermaid
flowchart LR
    A[RPLIDAR] -->|serial| B[sllidar_node]
    B -->|/scan| C[rf2o_laser_odometry_node]
    C -->|/odom_rf2o + TF| D[odometry]
```

---

## 1. Build

> **Do not run a bare `colcon build --symlink-install` on this Pi 4.**
> colcon invokes each package as `cmake --build ... -- -j4 -l4` and builds both
> packages concurrently — up to 8 `g++` jobs on a 4-core board with 3.7 GB RAM
> and no swap. The resulting memory pressure wedges the SD/MMC controller, and
> because the root filesystem *and* the Wi-Fi radio share the MMC/SDIO bus, the
> Pi simultaneously loses disk I/O and networking. SSH drops, cannot reconnect,
> and the board must be power-cycled.

Prefer the wrapper, which caps the build to one compiler job and one package at
a time:

```bash
cd ~/firefighter_ws
./build.sh
```

The underlying command it runs:

```bash
cd ~/firefighter_ws
source /opt/ros/jazzy/setup.bash
MAKEFLAGS="-j1 -l1" colcon build --symlink-install --executor sequential
source install/setup.bash
```

`JOBS=2 ./build.sh` is usually still safe if the Pi is otherwise idle.

See [README → Build the Workspace](README.md#1-build-the-workspace) for the
hardening steps (zram swap, `earlyoom`, USB-SSD root) that make builds robust.

---

## 2. Find the LiDAR port

```bash
ls -l /dev/ttyUSB* /dev/ttyACM* /dev/serial/by-id/ 2>/dev/null
```

| Wiring | Port |
|---|---|
| USB adapter (typical RPLIDAR dongle) | `/dev/ttyUSB0` |
| Direct to GPIO pins 8 (TXD) / 10 (RXD) | `/dev/ttyS0` |

Prefer the stable by-id path so the number doesn't change:

```bash
ls -l /dev/serial/by-id/
```

---

## 3. Permissions (if needed)

```bash
sudo chmod 777 /dev/ttyUSB0
```

---

## 4. Run the LiDAR driver

```bash
cd ~/firefighter_ws && source install/setup.bash
ros2 launch sllidar_ros2 sllidar_a1_launch.py serial_port:=/dev/ttyUSB0
```

Use the launch file that matches your model (e.g. `sllidar_a2m8_launch.py`, `sllidar_s1_launch.py`, …). Note different models use different `serial_baudrate`.

### Start the motor (if no scan appears)

The A1 motor doesn't always auto-start. If `/scan` stays silent:

```bash
ros2 service call /start_motor std_srvs/srv/Empty "{}"
```

### Verify data is flowing

```bash
ros2 topic hz /scan          # should show ~7–10 Hz
ros2 topic echo /scan --once # should print a LaserScan message
```

---

## 5. Run the odometry

```bash
cd ~/firefighter_ws && source install/setup.bash
ros2 launch rf2o_laser_odometry rf2o_laser_odometry.launch.py
```

The node looks up the transform `base_link → laser`, so add a static transform for the LiDAR's physical offset on the robot (zero here; adjust to your mount):

```bash
ros2 run tf2_ros static_transform_publisher 0 0 0 0 0 0 base_link laser
```

Defaults: reads `/scan`, publishes `/odom_rf2o`, TF `odom → base_link`.

---

## 6. Viewing the data

### Foxglove Studio (recommended, works headless over SSH)

```bash
source /opt/ros/jazzy/setup.bash
ros2 launch foxglove_bridge foxglove_bridge_launch.xml port:=8765
```

Then open <https://studio.foxglove.dev/> in a browser, connect to `ws://<pi-ip>:8765`, and add a **3D** panel with topic `/scan` (frame `laser`).

### ASCII radar view (terminal, no display needed)

```bash
cd ~/firefighter_ws && source install/setup.bash && python3 scripts/ascii_lidar_view.py
```

### Operations dashboard (browser)

Run the server on the Pi after sourcing the ROS 2 workspace:

```bash
cd ~/firefighter_ws && source install/setup.bash
python3 scripts/robot_dashboard.py
```

From a browser on the same trusted network, open `http://<pi-ip>:8080/`.

The page shows the LiDAR scan (2D, plus an optional 3D view) alongside the
robot's operational state: beacon alerts with RSSI and an estimated range, the
mobility ESP32's link / mode / e-stop flags, the mission FSM state and
suppression, wheel (`/wheel_odom`) vs laser (`/odom_rf2o`) odometry, a per-topic
rate and freshness table, and a rolling event log. A row of status tiles under
the header sums up mission, flame, beacon, drive, speed and battery at a glance,
and the LiDAR view is drawn with the robot's forward direction up. Anything that needs attention
is raised as a banner at the top: fire / smoke, a latched e-stop, an encoder
fault, a stale or down ESP32 link, an aborted mission. While a flame is being
tracked, its bearing and range are drawn on the 2D scan.

If the page loses the dashboard server it says `DASHBOARD OFFLINE` and dims
every panel - the values underneath are the last ones received, not live. The
LiDAR view is labelled the same way when `/scan` stops arriving.

Two optional live feeds are on by default and cost nothing until they are on
screen - the page only fetches them while they are showing:

- **Thermal camera** - the `/thermal/image` frame (16x12, deg C) as a heat map
  with the hottest pixel outlined; hover a pixel for its temperature. **Hide**
  on the card stops the stream.
- **Map** - a third view next to *Top-down* and *3D*: the `/map` occupancy grid
  from SLAM Toolbox (or `map_server` when `slam:=false`) with the robot, its
  trail, the live scan, the mission goal and the flame bearing drawn on it.
  It follows the robot at the chosen range; **Whole map** fits everything
  mapped so far. The robot is placed with the `map -> base_link` transform, so
  the view says so when that transform is missing or stale.

To leave either out entirely, start the server with an empty topic:

```bash
python3 scripts/robot_dashboard.py --thermal-topic "" --map-topic ""
```

`--thermal-topic`, `--map-topic` and `--base-frame` also point them at other
names.

For volumetric LiDAR data, pass a `PointCloud2` topic such as:

```bash
python3 scripts/robot_dashboard.py --pointcloud-topic /points
```

This RPLIDAR publishes planar `LaserScan` data; its 3D view is therefore flat
unless another node publishes a `PointCloud2`. Every watched topic can be
overridden (`--scan-topic`, `--beacon-topic`, `--odom-topic`,
`--diagnostics-topic`, ...) - run with `--help` for the full list. The server
binds to all network interfaces on port 8080 and has no authentication, so only
run it on a trusted network.

### Tweakable parameters

```bash
python3 scripts/ascii_lidar_view.py --ros-args \
  -p scan_topic:=/scan \
  -p max_range:=10.0 \
  -p size:=61 \
  -p rate:=15.0
```

| Param | Default | Meaning |
|---|---|---|
| `scan_topic` | `/scan` | LaserScan topic to read |
| `max_range` | `6.0` | View radius in meters |
| `size` | `41` | Grid width/height in characters |
| `rate` | `10.0` | Refresh rate (Hz) |

### RViz2 (needs a display)

```bash
rviz2 -d $(ros2 pkg prefix sllidar_ros2)/share/sllidar_ros2/rviz/sllidar_ros2.rviz
```

---

## Troubleshooting

- **`colcon: command not found`** — `sudo apt install python3-colcon-common-extensions`
- **No `/dev/ttyUSB*`** — check the USB cable/power; `lsusb` should show a `CP210x` / `CH340` / `FTDI` device.
- **Node runs but no scan** — call `/start_motor` (see §4).
- **Scan freezes after a while** — the motor has stalled; call `/start_motor` again, or power the LiDAR from a powered USB hub.

---

## 7. Full stack (SLAM + Nav2 + mission)

The whole robot comes up from one launch file:

```bash
cd ~/firefighter_ws && ./build.sh && source install/setup.bash
ros2 launch firefighter_bringup bringup.launch.py
```

First-time machine setup (Pi or WSL2 simulation) is in [`setup.md`](../setup.md).

That starts the robot model, the LiDAR, `rf2o`, the `robot_localization` EKF, the ESP32 bridge,
thermal perception, SLAM Toolbox, Nav2, the mission FSM and RViz. See
[`src/firefighter_bringup/README.md`](../src/firefighter_bringup/README.md) for the
full argument list and the TF-ownership diagram.

```bash
# mapping only, no Nav2
ros2 launch firefighter_bringup bringup.launch.py nav2_enabled:=false

# save the map once you have driven around
ros2 run nav2_map_server map_saver_cli -f ~/firefighter_ws/maps/map

# later: localize against the saved map instead of mapping
ros2 launch firefighter_bringup bringup.launch.py slam:=false
```

### TF ownership

Exactly one node publishes each transform. This is the thing that most often goes
wrong:

```
map ──(slam_toolbox)──> odom ──(EKF)──> base_link ──(robot_state_publisher)──> laser
                                                └──(robot_state_publisher)──> thermal_camera
```

`rf2o` and the bridge both publish odometry with `publish_tf: false` precisely so
the EKF can own `odom → base_link`. Running the old `rf2o_laser_odometry.launch.py`
(which defaults to `publish_tf: true`) **alongside** the bringup file will give
`base_link` two parents — check `ros2 node list` if TF looks unstable.

### Checking it is healthy

```bash
ros2 run tf2_tools view_frames          # one parent per frame
ros2 topic hz /scan /odometry/filtered /thermal/image
ros2 lifecycle get /slam_toolbox /controller_server /planner_server
ros2 topic echo /firefighter_mission/state
```

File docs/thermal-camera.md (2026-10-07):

# Thermal Camera — Melexis MLX90641

> **Status:** sensor identified and **verified working** (2026-10-07).
> Thermal perception / ML integration is still pending.

## 1. What the robot actually carries

| Property | Value |
|---|---|
| Part | **Melexis MLX90641** — 16 × 12 = **192-pixel** IR array |
| Bus / address | I²C bus 1 (`/dev/i2c-1`), address **`0x33`** |
| Supply | 3.3 V (measured `Vdd ≈ 3.29 V`) |
| Field of view | depends on the lens variant (55°×35° or 110°×70°) |

### Wiring (Raspberry Pi 40-pin header)

A 4-wire I²C device on the Pi's primary I²C bus (`i2c-1`). GPIO2/GPIO3 already
have pull-ups on the Pi, so **no external resistors are needed**.

| MLX90641 | Pi signal | GPIO | Physical pin |
|---|---|---|---|
| VCC | 3V3 | — | 1 (or 17) |
| GND | GND | — | 6 (or 9, 14, 20, 25, 30, 34, 39) |
| SDA | I²C1 SDA | GPIO2 | 3 |
| SCL | I²C1 SCL | GPIO3 | 5 |

```text
MLX90641                     Raspberry Pi 40-pin header
  VCC ────────────────────── 3V3    (pin 1 / 17)
  GND ────────────────────── GND    (pin 6 / 9 / 14 / 20 / 25 / 30 / 34 / 39)
  SDA ────────────────────── GPIO2  (pin 3)   I2C1 SDA
  SCL ────────────────────── GPIO3  (pin 5)   I2C1 SCL
```

> GPIO2/GPIO3 are the dedicated I²C1 pins, enabled by `dtparam=i2c_arm=on` in
> `/boot/firmware/config.txt`. Verify the wiring with `i2cdetect -y 1` — the
> sensor must answer at **`0x33`**.

The project originally assumed the robot carried a **Melexis MLX90640 (32 × 24 =
768 px)** — that assumption is baked into the old `adafruit-circuitpython-mlx90640`
dependency and the README. **It is incorrect.**

The MLX90640 and MLX90641 are pin- and I²C-compatible:

* same I²C address `0x33`,
* same register map (`EEPROM @ 0x2400`, pixel RAM `@ 0x0400`, control `@ 0x800D`,
  status `@ 0x8000`),

but they have **different EEPROM calibration layouts**. Using the wrong driver
therefore *silently mis-parses* the calibration instead of failing cleanly.

## 2. Identifying which part you have

A plain I²C scan **cannot** distinguish them — both answer at `0x33`. The vendor
libraries use a single EEPROM bit as the device selector:

* EEPROM word index **10** (`eeData[10]`), **bit 6** (`0x40`)
  * **set (1)** → **MLX90641** (`MLX90641_CheckEEPROMValid()` requires it)
  * **clear (0)** → **MLX90640**

On this robot:

```text
$ i2cdetect -y 1              # 0x33 is the only device on the bus
     0  1  2  3  4  5  6  7  8  9  a  b  c  d  e  f
30: -- -- -- 33 -- -- -- -- -- -- -- -- -- -- -- --

eeData[10] = 0x0AD9  ->  bit6 = 1  ->  MLX90641
```

## 3. Symptom with the wrong (MLX90640) driver

`adafruit-circuitpython-mlx90640` fails on this sensor:

```text
RuntimeError: More than 4 outlier pixels     # raised while constructing MLX90640(i2c)
ValueError: math domain error                # later, inside getFrame()
```

**Do not read this as a faulty or counterfeit sensor** — it is a part mismatch.
The hardware is healthy (verified in §5).

## 4. How to read it

There is **no MLX90641 driver on PyPI**. Drive it with the vendor C library
([`melexis/mlx90641-library`](https://github.com/melexis/mlx90641-library)) plus a
small Linux `/dev/i2c-1` backend.

### 4.1 The reader lives in this repo

The reader and its build script are vendored under
[`scripts/thermal/`](../scripts/thermal/):

| File | Purpose |
|---|---|
| `scripts/thermal/mlx90641_frames.cpp` | Linux I²C backend for the vendor API + CSV frame dump |
| `scripts/thermal/build.sh` | clones `melexis/mlx90641-library` (to `$MLX90641_LIB`, default `/tmp/mlx90641lib`) and compiles the reader |
| `scripts/thermal_frames.py` | captures frames and renders PNG heat maps |

The vendor library is the only supported path — there is no MLX90641 package on
PyPI.

### 4.2 The I²C backend (`scripts/thermal/mlx90641_frames.cpp`)

Implements the five functions the vendor API expects
(`MLX90641_I2CInit/Read/Write/GeneralReset/FreqSet`). 16-bit words are **MSB
first**.

```cpp
#include <cstdint>
#include <cstdio>
#include <fcntl.h>
#include <unistd.h>
#include <sys/ioctl.h>
#include <linux/i2c.h>
#include <linux/i2c-dev.h>
#include "MLX90641_I2C_Driver.h"

static int g_fd = -1;
static const char *g_dev = "/dev/i2c-1";

void MLX90641_I2CInit(void) {
    if (g_fd >= 0) return;
    g_fd = open(g_dev, O_RDWR);
    if (g_fd < 0) perror("open /dev/i2c-1");
}

void MLX90641_I2CFreqSet(int) { /* the kernel owns the clock */ }

int MLX90641_I2CGeneralReset(void) {
    if (g_fd < 0) return -1;
    uint8_t cmd[2] = {0x00, 0x06};          // general-call software reset
    if (write(g_fd, cmd, 2) != 2) return -1;
    usleep(1000);
    return 0;
}

int MLX90641_I2CRead(uint8_t slaveAddr, uint16_t startAddress,
                     uint16_t nMemAddressRead, uint16_t *data) {
    if (g_fd < 0) return -1;
    uint8_t addr[2] = {(uint8_t)(startAddress >> 8), (uint8_t)(startAddress & 0xFF)};
    static uint8_t buf[4096];
    if (2u * nMemAddressRead > sizeof(buf)) return -1;

    struct i2c_msg msgs[2];
    msgs[0].addr = slaveAddr; msgs[0].flags = 0;        msgs[0].len = 2;                msgs[0].buf = addr;
    msgs[1].addr = slaveAddr; msgs[1].flags = I2C_M_RD; msgs[1].len = 2 * nMemAddressRead; msgs[1].buf = buf;

    struct i2c_rdwr_ioctl_data xfer = { msgs, 2 };
    if (ioctl(g_fd, I2C_RDWR, &xfer) < 0) return -1;

    for (int i = 0; i < nMemAddressRead; i++)
        data[i] = (uint16_t)buf[2 * i] * 256u + buf[2 * i + 1];
    return 0;
}

int MLX90641_I2CWrite(uint8_t slaveAddr, uint16_t writeAddress, uint16_t data) {
    if (g_fd < 0) return -1;
    uint8_t cmd[4] = {(uint8_t)(writeAddress >> 8), (uint8_t)(writeAddress & 0xFF),
                      (uint8_t)(data >> 8),         (uint8_t)(data & 0xFF)};
    struct i2c_msg msg = { slaveAddr, 0, 4, cmd };
    struct i2c_rdwr_ioctl_data xfer = { &msg, 1 };
    return ioctl(g_fd, I2C_RDWR, &xfer) < 0 ? -1 : 0;
}
```

### 4.3 Frame read loop

The repo reader emits the 16×12 frame as **CSV on stdout** (diagnostics on
stderr); this is the essential loop:

```cpp
#include <cstdio>
#include <cstdint>
#include "MLX90641_API.h"
#include "MLX90641_I2C_Driver.h"

#define ADDR 0x33

int main(void) {
    MLX90641_I2CInit();

    static uint16_t ee[832];
    if (MLX90641_DumpEE(ADDR, ee)) { printf("DumpEE failed\n"); return 1; }
    printf("eeData[10]=0x%04X deviceSelect=%d\n", ee[10], (ee[10] >> 6) & 1);

    static paramsMLX90641 p;
    if (MLX90641_ExtractParameters(ee, &p)) { printf("ExtractParameters failed\n"); return 1; }

    float emissivity = MLX90641_GetEmissivity(&p);
    if (emissivity <= 0.0f || emissivity > 1.0f) emissivity = 0.95f;

    static uint16_t frame[242];
    static float to[192];

    for (int k = 0; k < 3; k++) {
        if (MLX90641_GetFrameData(ADDR, frame) < 0) continue;
        float vdd = MLX90641_GetVdd(frame, &p);
        float ta  = MLX90641_GetTa(frame, &p);
        MLX90641_CalculateTo(frame, &p, emissivity, ta, to);

        float mn = 1e9f, mx = -1e9f, sum = 0;
        for (int i = 0; i < 192; i++) { if (to[i]<mn) mn=to[i]; if (to[i]>mx) mx=to[i]; sum+=to[i]; }
        printf("frame %d: Vdd=%.2fV Ta=%.2fC  Tmin=%.2f Tmax=%.2f Tmean=%.2f  subpage=%d\n",
               k, vdd, ta, mn, mx, sum/192.0f, frame[241]);
    }

    printf("\nThermal image 16x12 (deg C):\n");
    for (int r = 0; r < 12; r++) {
        for (int c = 0; c < 16; c++) printf("%7.1f", to[r * 16 + c]);
        printf("\n");
    }
    return 0;
}
```

### 4.4 Build, run, render

```bash
bash scripts/thermal/build.sh          # clone vendor lib + compile the reader
./scripts/thermal/mlx90641_frames 3    # 3 frames of 16x12 CSV on stdout

uv run scripts/thermal_frames.py -n 3  # capture + render PNGs (default docs/images)
```

> The user account only needs read access to `/dev/i2c-1` (e.g. membership of the
> `i2c` group). No `sudo` is required on this robot.

## 5. Sample frames

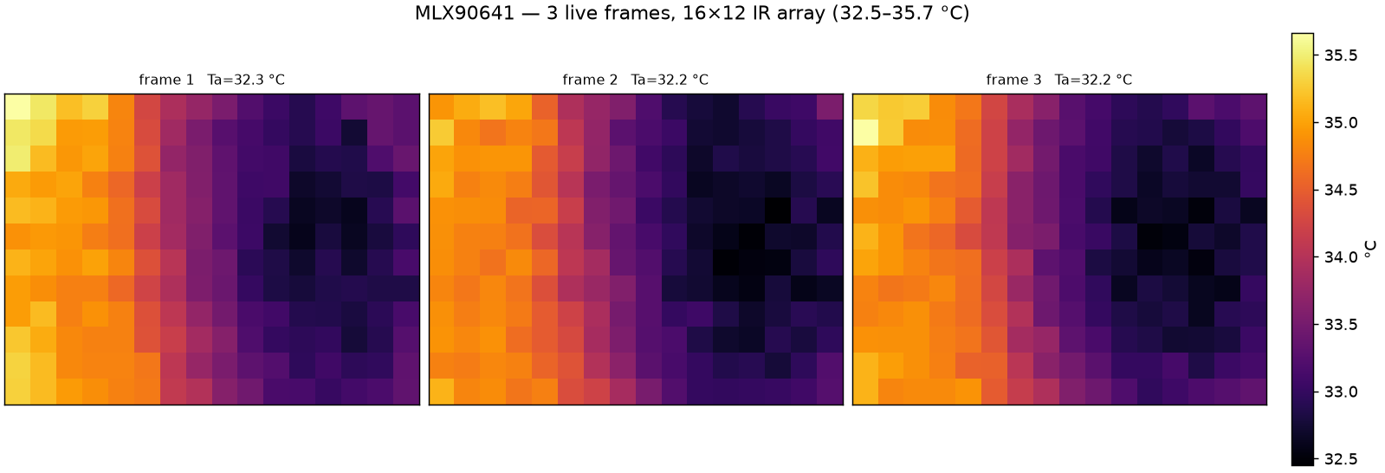
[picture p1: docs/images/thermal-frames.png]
Three live MLX90641 frames


Individual frames: [1](images/thermal-frame-01.png) ·
[2](images/thermal-frame-02.png) ·
[3](images/thermal-frame-03.png) — produced by
`uv run scripts/thermal_frames.py -n 3`.

Raw numeric dump from two runs a few seconds apart (a warm object fills the
centre/right):

```text
MLX90641_DumpEE            -> 0
eeData[10]=0x0AD9  deviceSelect(bit6)=1
MLX90641_ExtractParameters -> 0
frame 0: Vdd=3.29V  Ta=32.32C  Tmin=29.24  Tmax=36.23  Tmean=33.43  subpage=0
frame 1: Vdd=3.29V  Ta=32.32C  Tmin=29.15  Tmax=36.14  Tmean=33.33  subpage=1
frame 2: Vdd=3.29V  Ta=32.31C  Tmin=29.22  Tmax=36.29  Tmean=33.40  subpage=0

Thermal image 16x12 (deg C):
   30.0   29.5   29.7   29.8   30.2   31.6   32.5   33.5   34.0   34.4   34.4   34.0   32.7   30.2   29.6   32.1
   29.9   29.5   30.0   29.8   30.6   32.5   33.3   33.9   34.4   34.9   35.0   34.6   34.1   30.0   29.3   31.1
   29.4   30.0   29.2   29.8   31.6   33.1   33.6   34.2   34.8   35.2   35.4   35.1   34.7   31.3   29.2   30.3
   29.7   29.7   29.4   30.4   32.9   33.4   34.0   34.6   35.2   35.5   35.7   35.5   35.0   33.6   29.7   30.2
   29.6   29.6   31.1   31.7   33.2   33.8   34.2   34.7   35.3   35.6   35.9   35.7   35.3   34.6   30.4   30.1
   29.5   29.6   30.1   32.5   33.3   33.8   34.4   34.8   35.4   35.8   35.8   35.7   35.2   34.7   31.8   30.4
   29.7   30.0   31.2   33.3   33.8   34.1   34.6   34.9   35.3   35.7   35.9   35.6   35.4   34.9   33.3   30.6
   29.5   30.3   32.5   33.2   33.9   34.3   34.6   35.2   35.5   35.7   35.7   35.8   35.5   35.0   34.5   31.2
   29.8   30.3   32.8   33.7   34.1   34.5   34.8   35.2   35.6   35.8   35.9   35.8   35.7   35.3   34.9   32.0
   29.4   31.3   33.3   33.6   34.2   34.6   35.0   35.3   35.5   35.8   35.8   35.8   35.8   35.3   35.1   33.0
   30.0   32.5   33.5   33.9   34.4   34.7   35.1   35.5   35.6   36.0   36.0   36.3   36.0   35.5   35.3   33.5
   30.6   33.3   33.6   34.2   34.5   34.8   35.2   35.5   35.9   36.1   36.1   36.1   35.8   35.9   35.4   34.3
```

```text
frame 0: Vdd=3.29V  Ta=32.31C  Tmin=29.22  Tmax=36.22  Tmean=33.38  subpage=1

Thermal image 16x12 (deg C):
   29.8   29.5   29.7   29.7   29.9   31.5   32.4   33.4   34.1   34.5   34.5   34.2   32.5   30.1   29.5   31.9
   29.6   29.5   30.0   29.6   30.6   32.5   33.2   33.8   34.4   34.9   35.2   34.7   33.9   29.8   29.2   31.1
   29.7   29.8   29.4   29.6   31.7   33.2   33.7   34.2   34.9   35.2   35.4   35.1   34.7   31.5   29.4   30.4
   29.6   29.4   29.5   30.4   32.6   33.2   34.0   34.4   35.1   35.6   35.8   35.5   34.9   33.5   29.5   30.1
   29.6   29.7   31.0   31.4   33.1   33.8   34.2   34.6   35.0   35.6   35.8   35.8   35.1   34.6   30.4   30.2
   29.4   29.4   29.9   32.7   33.3   33.8   34.4   34.8   35.1   35.8   35.9   35.6   35.2   34.7   31.7   30.4
   29.7   30.1   31.1   33.2   33.8   34.0   34.5   35.0   35.3   35.6   35.8   35.7   35.1   35.0   33.4   30.8
   29.6   30.1   32.2   33.4   33.8   34.2   34.8   35.2   35.3   35.7   35.9   35.8   35.3   35.2   34.3   31.0
   29.8   30.4   33.1   33.5   34.0   34.5   34.7   35.0   35.5   35.7   36.0   35.7   35.6   35.1   35.0   32.0
   29.4   31.4   33.2   33.7   34.2   34.4   34.9   35.2   35.5   35.7   36.0   35.7   35.7   35.4   35.2   32.8
   29.8   32.6   33.6   33.7   34.4   34.8   35.1   35.4   35.6   35.8   36.0   35.9   35.8   35.5   35.3   33.5
   30.4   33.2   33.8   34.1   34.5   34.9   35.1   35.5   35.6   36.0   36.2   36.1   35.9   35.7   35.7   34.3
```

Notes:

* The **1.0 EEPROM emissivity** means the 192 px are reported as absolute
  temperatures with the sensor's own emissivity (1.0 → ideal black-body). For a
  real flame target, use the EEPROM value (or override, e.g. 0.95) and pass the
  measured ambient `Ta` as the reflected temperature `tr`.

## 6. Integration plan

1. **Drop the wrong dependency.** The thermal sensor is **not** an MLX90640; remove
   `adafruit-circuitpython-mlx90640` from `pyproject.toml` (done).
2. **Add a driver.** No PyPI MLX90641 package exists, so either
   * vendor the small C reader above behind a ROS 2 node, or
   * port the vendor C API (`MLX90641_ExtractParameters` / `CalculateTo`) to Python.
3. **Publish a `sensor_msgs/Image`** (or `firefighter_interfaces/FlameEvent`) from
   the 192-pixel (16 × 12) frame; update the pixel geometry everywhere — **192, not
   768**.
4. **Flame localization** then consumes the thermal image (see
   [`src/firefighter_interfaces/msg/FlameEvent.msg`](../src/firefighter_interfaces/msg/FlameEvent.msg)).

## 7. References

* Vendor library: <https://github.com/melexis/mlx90641-library>
* MLX90641 datasheet: <https://www.melexis.com/en/product/MLX90641>
* MLX90640 (the *other* part — **not** used here): <https://www.melexis.com/en/product/MLX90640>
* Adafruit CircuitPython MLX90640 driver "outlier pixels" issue:
  <https://github.com/adafruit/Adafruit_CircuitPython_MLX90640/issues/19>

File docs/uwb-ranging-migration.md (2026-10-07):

# UWB (Ultra-Wideband) Ranging Migration Guide

This document defines the architecture, hardware integration, protocol changes, and migration roadmap for replacing interim RSSI-based proximity estimation with high-accuracy **Ultra-Wideband (UWB) Time-of-Flight ranging** between the Fire Beacon and the Robot Mobility ESP32.

---

## 1. Executive Summary

| Attribute | Current Interim Method (RSSI) | Target Upgrade (UWB ToF) |
|---|---|---|
| **Technology** | 2.4 GHz ESP-NOW Wi-Fi Signal Strength | IEEE 802.15.4a / 802.15.4z UWB (3.5–6.5 GHz) |
| **Accuracy** | $\pm 3\text{ to } 8\text{ meters}$ (qualitative proximity) | **$\pm 5\text{ to } 10\text{ cm}$ (exact physical distance)** |
| **Multipath Immunity** | Very Low (severe wall/object reflections) | **Very High** (nanosecond pulses isolate direct path) |
| **Smoke/Fire Penetration** | Medium | **High** (RF penetration through smoke and dust) |
| **Hardware Required** | ESP32 on-board Wi-Fi | Decawave DWM1000 or DWM3000 module per ESP32 |
| **Protocol** | `uint8_t rssi` in `MSG_BEACON_EVENT` | Millimeter distance in `MSG_BEACON_EVENT` / `MSG_BEACON_RANGE` |

---

## 2. Hardware Architecture

```mermaid
flowchart LR
    subgraph Beacon [Fire Beacon ESP32]
        Sensor[Flame / Smoke Sensor] --> B_ESP[ESP32 Sender]
        B_ESP <-->|SPI| B_UWB[DWM1000 / DWM3000 Anchor]
    end

    subgraph Robot [Robot Mobility ESP32]
        R_UWB[DWM1000 / DWM3000 Tag] <-->|SPI| R_ESP[ESP32 Receiver / Gateway]
        R_ESP --> Drivers[L298N Motors]
        R_ESP -->|UART2| Pi[Raspberry Pi / ROS 2]
    end

    B_UWB <===>|UWB Two-Way Ranging (ToF)| R_UWB
    B_ESP -.->|ESP-NOW Fallback Alert| R_ESP
```

### Recommended Hardware
* **Decawave DWM1000 / DWM3000** SPI Breakout boards (or Makerfabs ESP32 UWB modules).
* **Operating Band**: Channel 2 (3993.6 MHz) or Channel 5 (6489.6 MHz) for optimal indoor penetration.

### SPI Wiring to ESP32
Ensure these pins do not conflict with motor driver pins (`GPIO 14, 25, 26, 27, 32, 33`), encoders (`GPIO 18, 19, 22, 23`), or UART2 (`GPIO 16, 17`):

| DWM1000 Pin | Beacon ESP32 GPIO | Robot ESP32 GPIO | Function |
|---|---|---|---|
| **VCC** | 3.3V | 3.3V | Power supply (decoupled with 100 nF + 10 µF) |
| **GND** | GND | GND | Common ground |
| **SCK** | GPIO 18 | GPIO 5 | SPI Clock |
| **MISO** | GPIO 19 | GPIO 4 | SPI MISO |
| **MOSI** | GPIO 23 | GPIO 21 | SPI MOSI |
| **CS / NSS**| GPIO 5 | GPIO 15 | SPI Chip Select |
| **IRQ** | GPIO 4 | GPIO 13 | Hardware Interrupt (Rising Edge) |
| **RST** | GPIO 22 | GPIO 12 | Hardware Reset (Active Low) |

---

## 3. Ranging Protocol (Two-Way Ranging / TWR)

Single-Sided (SS-TWR) or Double-Sided (DS-TWR) Two-Way Ranging computes Time-of-Flight without requiring nanosecond clock synchronization:

```mermaid
sequenceDiagram
    autonumber
    participant Tag as Robot Tag (Initiator)
    participant Anchor as Beacon Anchor (Responder)

    Tag->>Anchor: UWB Poll Frame [Tx timestamp: t_round1]
    Note over Anchor: Anchor receives Poll [Rx timestamp: t_reply1]
    Anchor-->>Tag: UWB Response Frame [Tx timestamp: t_reply2]
    Note over Tag: Tag receives Response [Rx timestamp: t_round2]
    Tag->>Anchor: UWB Final Frame [Tx timestamp: t_final1]

    Note over Tag,Anchor: Time of Flight (ToF) = ((t_round1 * t_reply2) - (t_reply1 * t_final1)) / ...<br/>Distance (d) = ToF * c
```

---

## 4. Software & Firmware Changes

### 4.1 Arduino Library
* Install `DW1000-ng` or `decadriver` in the Arduino / PlatformIO environment.
* Initialize the UWB transceiver in `setup()`:
  ```cpp
  #include <DW1000Ng.hpp>
  // Configure SPI pins and antennas
  DW1000Ng::initialize(PIN_SS, PIN_IRQ, PIN_RST);
  DW1000Ng::setupStorageRegisters();
  ```

### 4.2 Framed Protocol Evolution (`firefighter_protocol.h`)
Update `MSG_BEACON_EVENT` (or introduce `MSG_BEACON_RANGE` `0x86`) to include measured distance in millimeters:

```cpp
// MSG_BEACON_EVENT (0x83):
// Payload (15 bytes):
//   uint32_t messageNumber (4B)
//   uint8_t  fireDetected  (1B)
//   uint8_t  smokeDetected (1B)
//   uint8_t  rssi          (1B)   - Interim Wi-Fi RSSI magnitude
//   uint16_t range_mm      (2B)   - UWB range in millimeters (0 if no UWB lock)
//   uint8_t  mac[6]        (6B)
```

### 4.3 ROS 2 Interface (`BeaconEvent.msg`)
Update `src/firefighter_interfaces/msg/BeaconEvent.msg`:
```text
std_msgs/Header header

uint32 message_number
bool fire_detected
bool smoke_detected
uint8 rssi               # Wi-Fi RSSI magnitude in dBm
float32 distance_m       # UWB distance in meters (0.0 if unavailable)
uint8[6] mac
```

### 4.4 Bridge Node (`firefighter_bridge`)
Unpack `range_mm` from payload and publish `distance_m = event.range_mm / 1000.0`.

---

## 5. Navigation & SLAM Integration

When UWB range is available in ROS 2:
1. **Trilateration / Range-Only SLAM**: With multiple beacons or a moving robot estimating positions over time, range measurements form circles intersecting at the fire source location $(x_f, y_f)$.
2. **Costmap Attraction Layer / Goal Generator**: Autonomously guide `/goal_pose` towards the beacon by driving down the distance gradient.
3. **Sensor Fusion**: Combine 2D LiDAR (`sllidar_ros2`) and laser odometry (`rf2o_laser_odometry`) with UWB range to pin the beacon coordinate onto the `/map` frame.

---

## 6. Migration Checklist

- [ ] Procure 2x Decawave DWM1000 or DWM3000 breakout modules.
- [ ] Connect SPI pins on the Beacon ESP32 and Robot Mobility ESP32 according to the pinout table.
- [ ] Implement Two-Way Ranging (TWR) using the `DW1000Ng` library.
- [ ] Add `range_mm` field to `firefighter_protocol.h` and `BeaconEvent.msg`.
- [ ] Update `protocol.py` codecs and `bridge_node.py` publisher.
- [ ] Add unit tests in `tests/test_protocol_codec.py` for UWB payload serialization.
- [ ] Verify $\pm 10\text{ cm}$ range accuracy in indoor smoke/obstacle test bench.

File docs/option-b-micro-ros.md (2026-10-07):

# Option B — micro-ROS on the Mobility ESP32 (deferred)

> **Status: not implemented.** The project currently ships **Option A** — a custom
> framed binary protocol over UART (`firefighter_protocol.h` + a Pi-side bridge
> node). This document exists so we can switch later without re-deriving the design.

---

## Why this is parked, not chosen

Option A won because it keeps the ESP32 firmware small, debuggable with any serial
monitor, and free of a heavyweight middleware. Option B becomes attractive if the
ROS 2 side grows (Nav2 integration, TF trees, action interfaces) and hand-maintaining
a custom protocol becomes the bottleneck.

---

## What changes conceptually

| | Option A (current) | Option B (micro-ROS) |
|---|---|---|
| ESP32 speaks | custom binary frames | ROS 2 (CDR) natively |
| Pi-side component | your `firefighter_bridge` node | `micro_ros_agent` (generic) |
| Topics/messages | defined by the frame IDs in `firefighter_protocol.h` | defined by `.msg` files / standard interfaces |
| Serial port owner | the bridge node | the micro-ROS agent |
| Firmware size | small | larger (client library, allocator, RMW) |

```mermaid
flowchart LR
    Beacon["ESP32 Beacon"] -->|ESP-NOW| ESP["ESP32 Mobility<br/>micro-ROS client"]
    ESP -->|"UART + micro-ROS XRCE-DDS"| Agent["micro_ros_agent<br/>(Raspberry Pi)"]
    Agent --> DDS["ROS 2 graph<br/>/cmd_vel, /odom, /beacon_event"]
```

The ESP-NOW beacon path **does not change** — the ESP32 still receives beacon packets
and republishes them as a ROS 2 topic.

---

## Prerequisites

### Raspberry Pi
```bash
# Jazzy agent (preferred if packaged for your distro)
sudo apt install ros-jazzy-micro-ros-agent
# otherwise build from source with the micro-ROS setup tool
#   ros2 run micro_ros_setup create_agent_ws.sh && ros2 run micro_ros_setup build_agent.sh
```

### ESP32 toolchain
Add the **`micro_ros_arduino`** library (Arduino IDE → Library Manager, or vendor it
into the sketch folder). It must be built with the same ESP32 Arduino core you flash
with (2.0.x here).

---

## Wiring

Identical to Option A — the physical link is unchanged:

| Pi | ESP32 |
|---|---|
| GPIO14 (TXD) | GPIO16 (RX) |
| GPIO15 (RXD) | GPIO17 (TX) |
| GND | GND |

UART1 (GPIO9/10) must **not** be used — wired to flash on WROOM modules.

> **Alternative transport:** because both boards have Wi-Fi, micro-ROS can also run
> over UDP (`rmw_microxrcedds` + `micro_ros_agent udp4 --port 8888`) with no cable at
> all. Trade-off: shared 2.4 GHz band with ESP-NOW and the Wi-Fi hotspot, and more
> latency jitter than a dedicated wire.

---

## Steps

### 1. Configure the micro-ROS transport (Pi side config, compiled into the ESP32)
Point the serial transport at UART2 pins, e.g. in the sketch before `setup()`:

```cpp
#define MICROROS_TRANSPORT_UART_PORT 2
#define MICROROS_TRANSPORT_SERIAL_INTERFACE 17   // TX
#define MICROROS_TRANSPORT_SERIAL_INTERFACE_RX 16 // RX
#include <micro_ros_arduino.h>
```

### 2. Flash a micro-ROS node
Replace the UART gateway code in `robot_mobility.ino` with a `rclc` executor node that:

- subscribes `geometry_msgs/Twist` → drives `setMotor(1/2, …)` (reuse the same motor helpers)
- publishes `nav_msgs/Odometry` → from the same `motor1_encoder_count` / `motor2_encoder_count`
- publishes `firefighter_interfaces/BeaconEvent` → from `OnDataRecv` (keep the ESP-NOW callback)
- keeps the **same watchdog**: if no `Twist` for `PI_TIMEOUT_MS`, `stopMotors()`

### 3. Run the agent on the Pi
```bash
source /opt/ros/jazzy/setup.bash
# free the port first (see runbook.md): disable serial console, chmod the device
ros2 run micro_ros_agent micro_ros_agent serial --dev /dev/ttyAMA0 -b 115200
```

### 4. Verify
```bash
ros2 node list        # should show the ESP32's node
ros2 topic hz /odom_wheels
ros2 topic pub /cmd_vel geometry_msgs/msg/Twist "{linear: {x: 0.1}}" -r 10
```

---

## Topic mapping (Option B)

| Direction | Topic | Type |
|---|---|---|
| Pi → ESP32 | `/cmd_vel` | `geometry_msgs/msg/Twist` |
| ESP32 → Pi | `/odom_wheels` | `nav_msgs/msg/Odometry` |
| ESP32 → Pi | `/beacon_event` | `firefighter_interfaces/msg/BeaconEvent` |
| ESP32 → Pi | `/diagnostics` | `diagnostic_msgs/msg/DiagnosticArray` |

This replaces, respectively, `MSG_SET_TWIST`, `MSG_WHEEL_ODOM`, `MSG_BEACON_EVENT`
and `MSG_STATUS` from `firefighter_protocol.h`.

---

## Trade-offs

**Pros**
- No custom framing/CRC code to maintain; standard tools (`ros2 topic`, rqt, Foxglove).
- `Twist`/`Odometry` drop straight into Nav2 and TF.
- The ESP32 becomes a first-class node — easier multi-robot / multiple-ESP32 setups.

**Cons**
- Larger, slower-to-build firmware; more RAM/flash pressure on the ESP32.
- The number of RX/TX buffers and the agent lifecycle add failure modes (agent down = robot silent).
- Harder to debug bare-metal: a bad allocator or transport config can wedge the node.
- The agent takes exclusive ownership of the serial port.

---

## Migration path (when to switch)

Switch if **two or more** of these become true:
1. You need Nav2 actions/services, not just a velocity stream.
2. More than one ESP32 joins the robot and you want them all as ROS nodes.
3. The custom protocol needs new message types more than ~once a month.
4. You want to inspect live data in Foxglove/rqt without writing a decoder.

Keeping the ESP-NOW beacon callback and the motor/encoder helper functions unchanged
makes the switch mostly a transport-layer swap.

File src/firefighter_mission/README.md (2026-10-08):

# firefighter_mission

Mission behaviour state machine: **beacon alert → navigate → search → suppress → verify**.

The sequencing logic is pure Python in `mission_fsm.py` (no ROS), so it is unit
tested without a ROS install (`tests/test_mission_fsm.py`). `mission_node.py` is a
thin adapter that maps ROS messages to FSM events and executes the returned actions.

## States

```
IDLE ──alert──> CONFIRMING ──2nd alert──> NAVIGATING ──reached──> SEARCHING
                    │                          │                      │
              timeout -> IDLE             abort/timeout          FLAME_FOUND
                                               │                      v
                                               │                APPROACHING
                                               │                      │ IN_RANGE
                                               │                      v
                                               │   FLAME_STILL_PRESENT  SUPPRESSING
                                               │        ┌──────── VERIFYING <──┐
                                               │        │ (max 3 attempts)     │
                                               └──────> ABORTED <──┘        COMPLETE -> IDLE
```

`ESTOP` from any state drops straight to `ABORTED`; only `RESET` leaves it.

## Topics

| Name | Type | Dir | Notes |
|---|---|---|---|
| `/beacon_event` | `BeaconEvent` | in | alert only when `fire && smoke` |
| `/flame_event` | `FlameEvent` | in | from `firefighter_perception` |
| `~/event` | `String` | in | **manual event injection** for bring-up |
| `navigate_to_pose` | `nav2_msgs/NavigateToPose` | action | navigation goal (when `use_nav2`) |
| `~/goal_pose` | `PoseStamped` | out | the goal, published for display |
| `/cmd_vel` | `Twist` | out | search spin, flame approach + stop (feeds the bridge) |
| `~/suppress` | `Bool` | out | extinguisher on/off |
| `~/state` | `String` | out | current state, on change |
| `/diagnostics` | `DiagnosticArray` | out | state, attempts, alerting MAC |
| `~/estop`, `~/reset` | `Trigger` | srv | drive the FSM directly |

## Run

```bash
cd ~/firefighter_ws && ./build.sh && source install/setup.bash
ros2 launch firefighter_mission mission.launch.py
```

## Bring-up without Nav2 or a thermal camera

With `use_nav2:=false` (or simply no Nav2 running) the node only publishes the goal
for display and waits for a `NAV_GOAL_REACHED` event, so the whole mission can be
driven by hand:

```bash
ros2 topic pub --once /firefighter_mission/event std_msgs/String "{data: nav_goal_reached}"
ros2 topic pub --once /firefighter_mission/event std_msgs/String "{data: flame_found}"
ros2 topic pub --once /firefighter_mission/event std_msgs/String "{data: in_range}"
ros2 topic pub --once /firefighter_mission/event std_msgs/String "{data: flame_extinguished}"
ros2 topic echo /firefighter_mission/state
```

Valid event names are exactly the `Event` enum values in `mission_fsm.py`.

Nav2 is now wired in: the goal goes out through the `navigate_to_pose` action and
arrival/abort come back as the same events. `use_nav2:=false` restores the manual
path above. The FSM itself never learned that Nav2 exists.

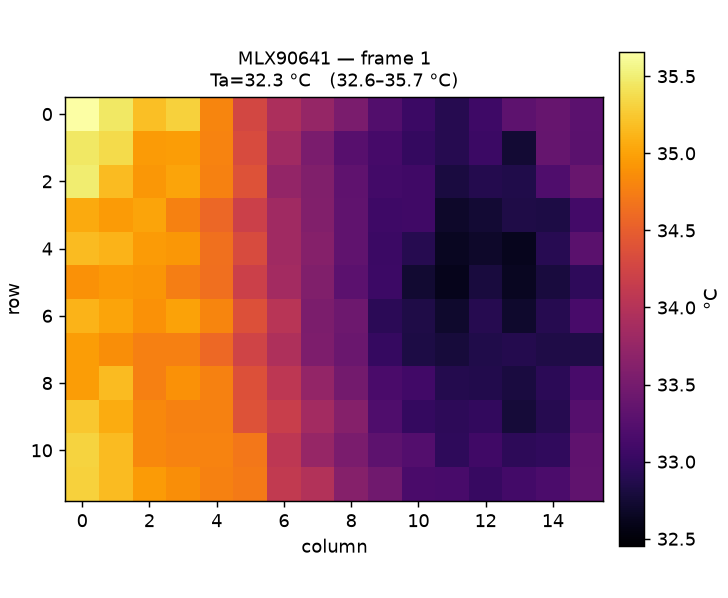
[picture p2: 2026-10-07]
docs/images/thermal-frame-01.png

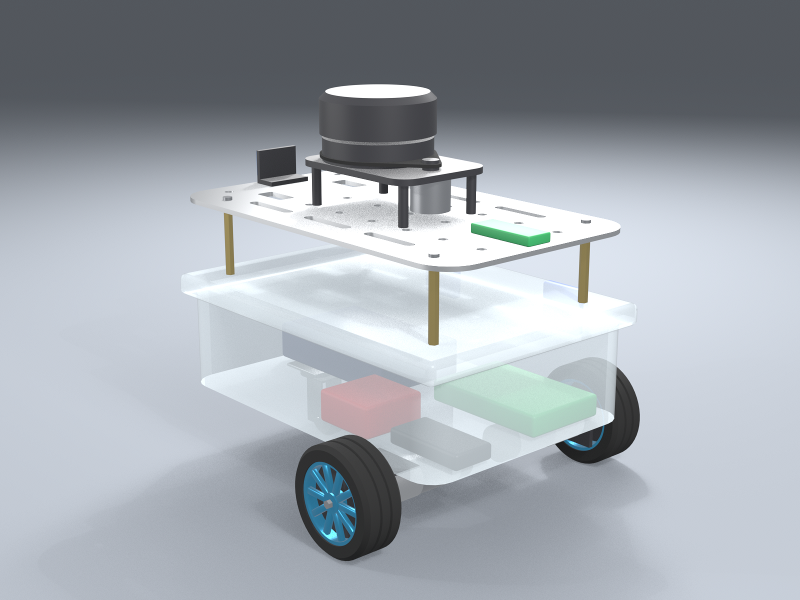
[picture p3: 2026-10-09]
model/renders/rear_left.png

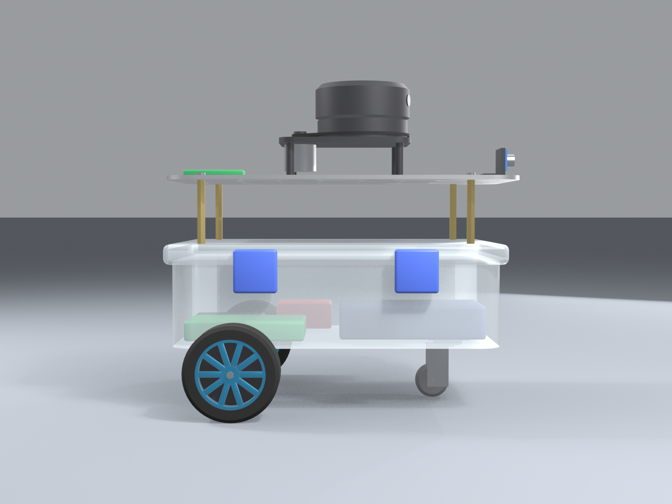
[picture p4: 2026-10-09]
model/renders/side.png

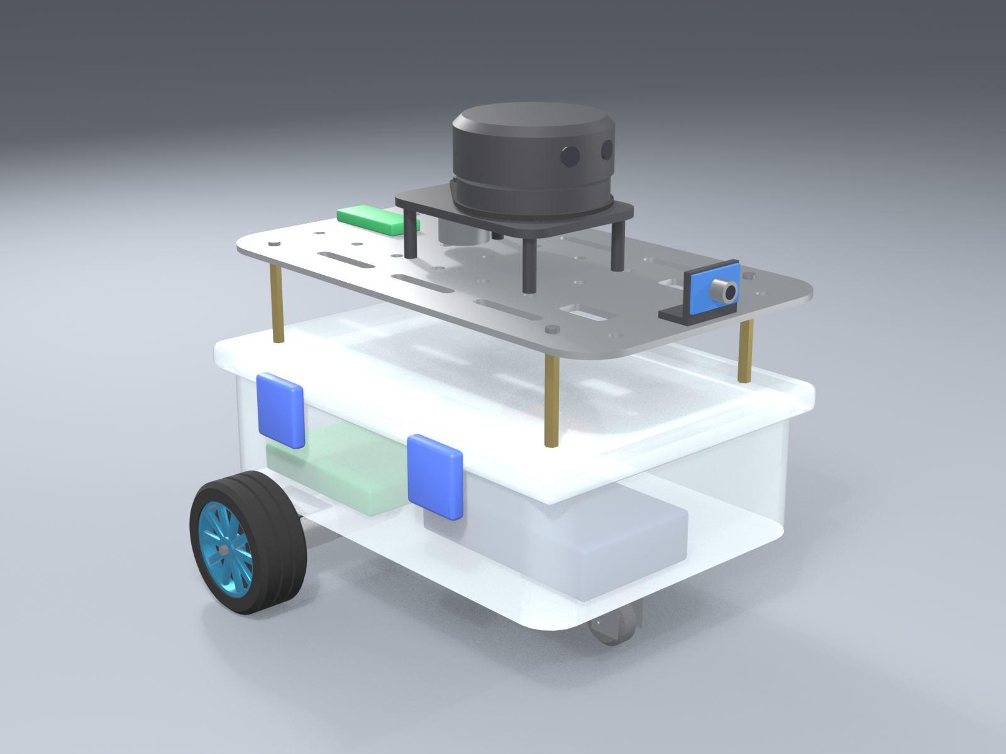
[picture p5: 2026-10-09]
model/renders/front_right.png

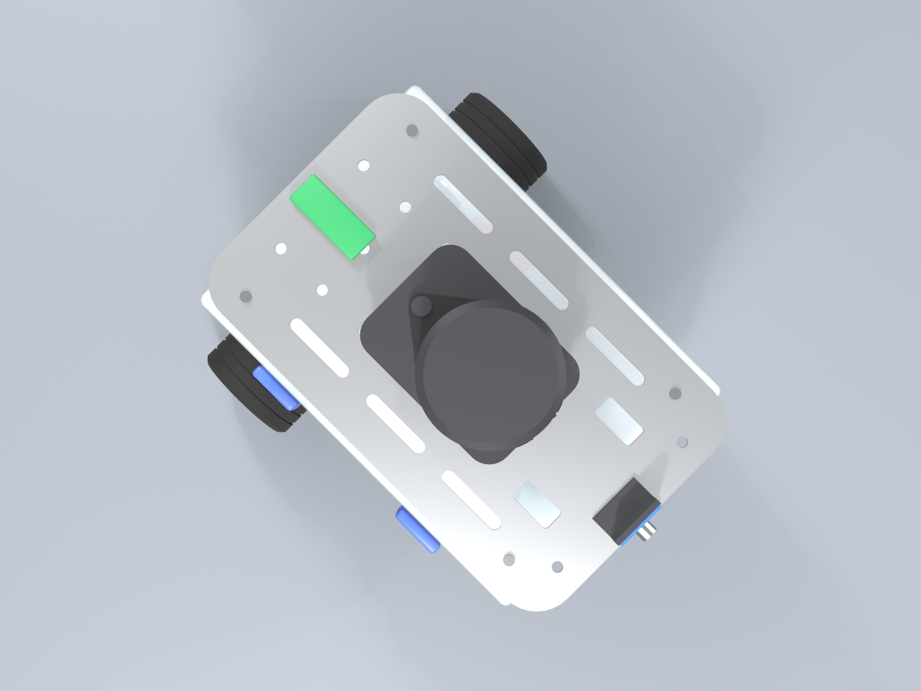
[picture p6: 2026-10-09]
model/renders/top.png

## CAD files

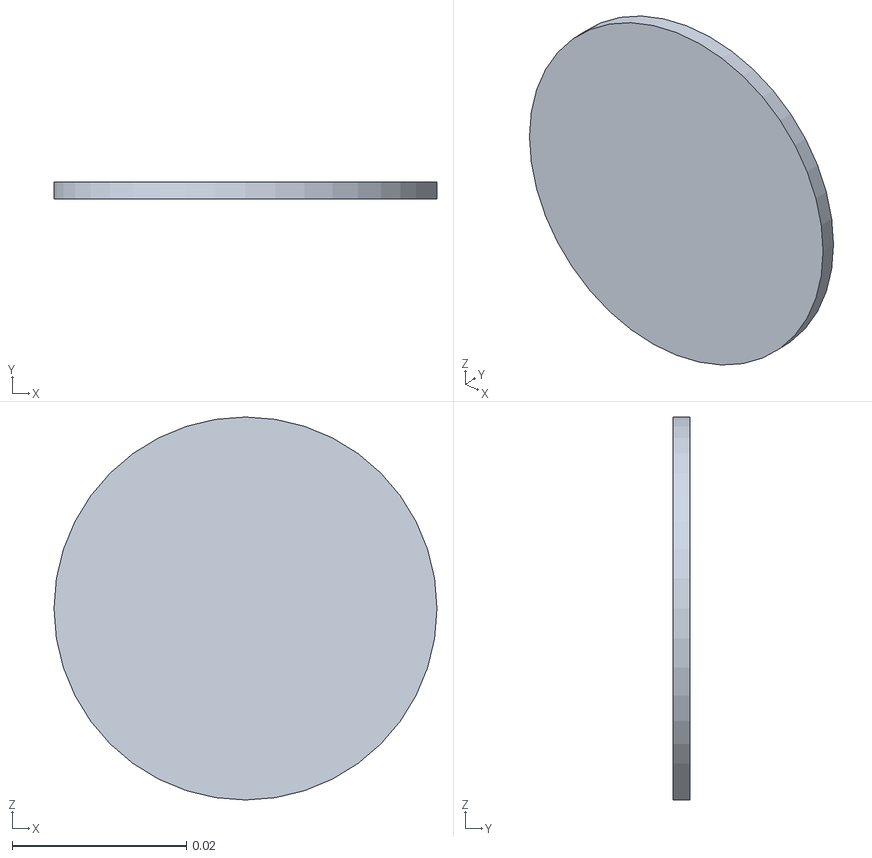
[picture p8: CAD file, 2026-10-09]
src/firefighter_description/meshes/left_wheel_visual_0.stl
0.044 x 0.002 x 0.044

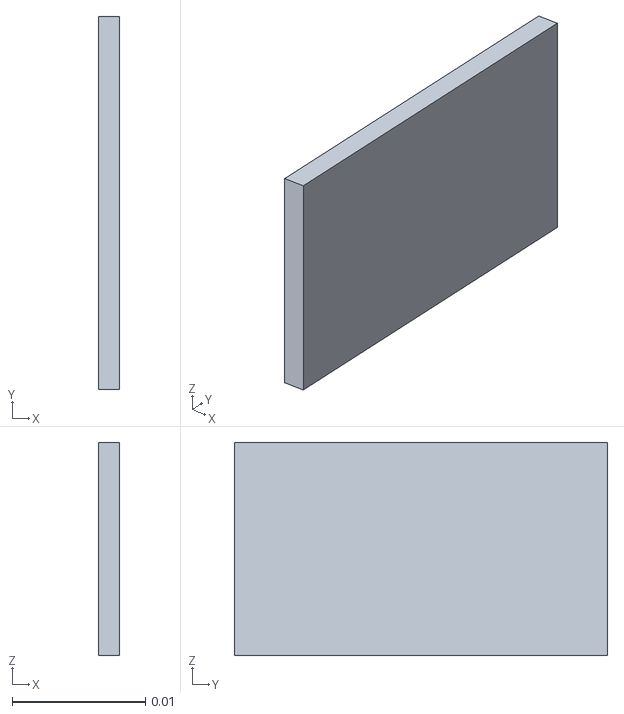
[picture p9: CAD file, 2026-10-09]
src/firefighter_description/meshes/thermal_camera_visual_1.stl
0.0016 x 0.028 x 0.016

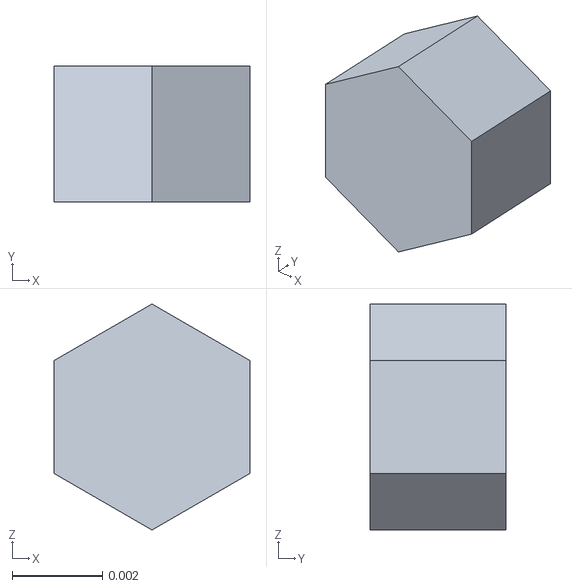
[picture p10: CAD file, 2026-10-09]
src/firefighter_description/meshes/left_wheel_visual_4.stl
0.00433 x 0.003 x 0.005

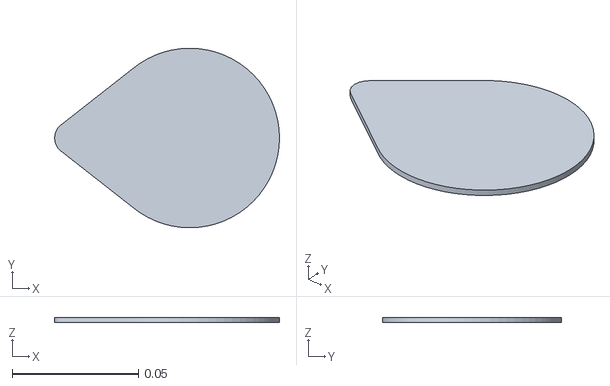
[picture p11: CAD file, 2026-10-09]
src/firefighter_description/meshes/laser_visual_2.stl
0.089 x 0.071 x 0.002

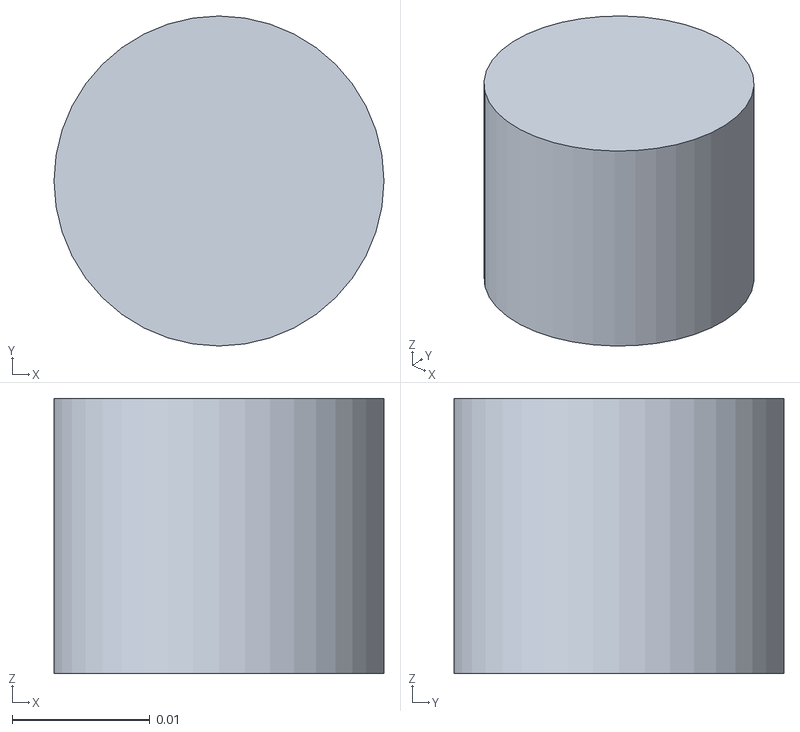
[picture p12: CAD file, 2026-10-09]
src/firefighter_description/meshes/laser_visual_3.stl
0.024 x 0.024 x 0.02

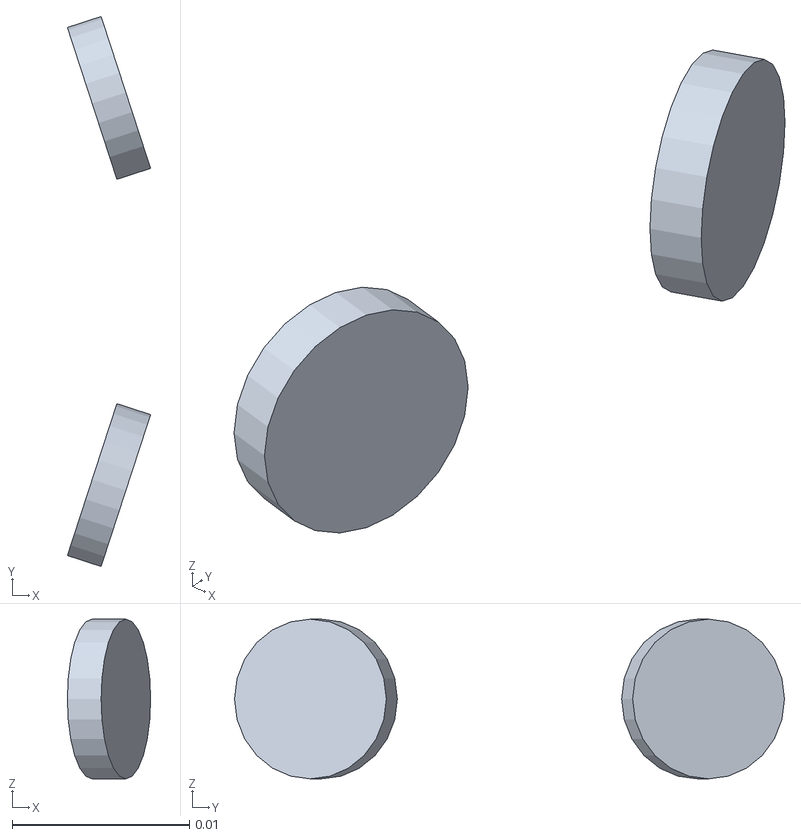
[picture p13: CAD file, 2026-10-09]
src/firefighter_description/meshes/laser_visual_1.stl
0.00469 x 0.031 x 0.009

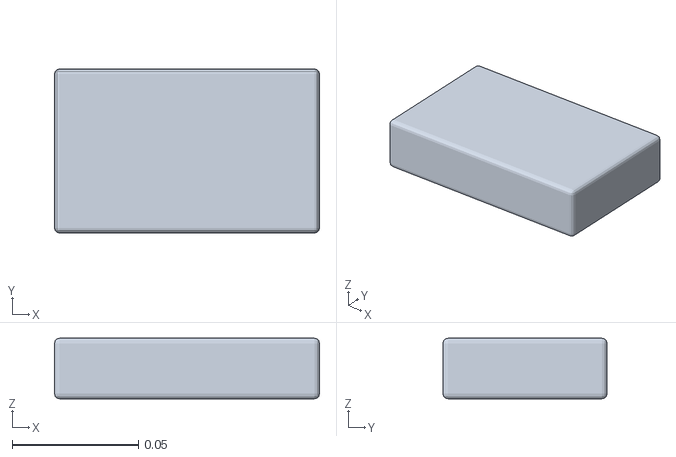
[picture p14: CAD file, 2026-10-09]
src/firefighter_description/meshes/base_link_visual_1.stl
0.105 x 0.065 x 0.024

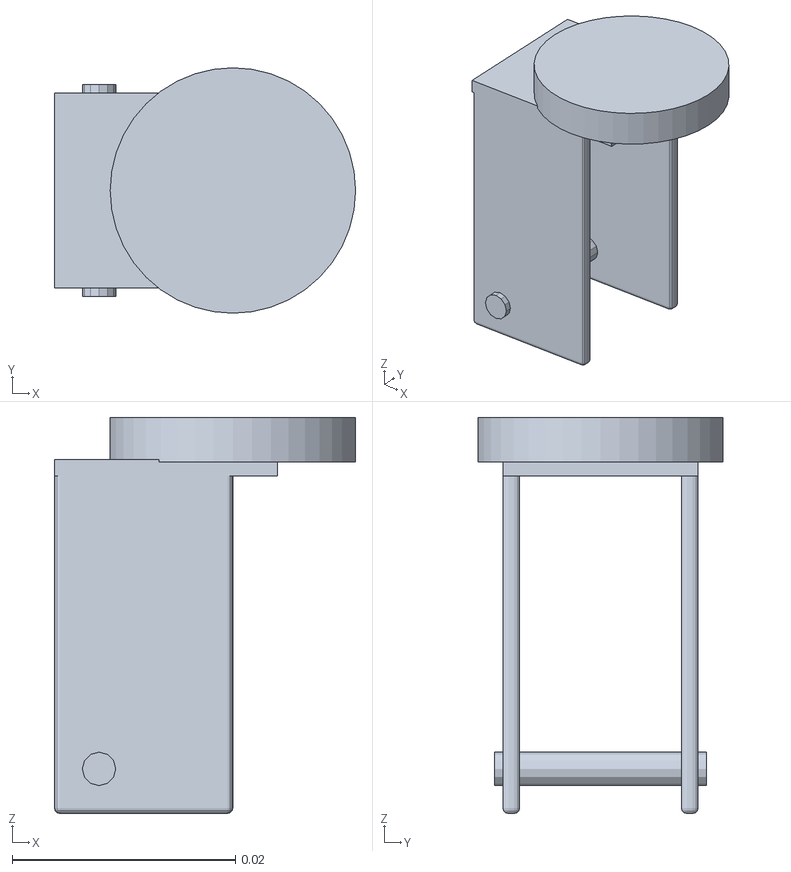
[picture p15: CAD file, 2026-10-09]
src/firefighter_description/meshes/caster_swivel_visual.stl
0.027 x 0.022 x 0.0355

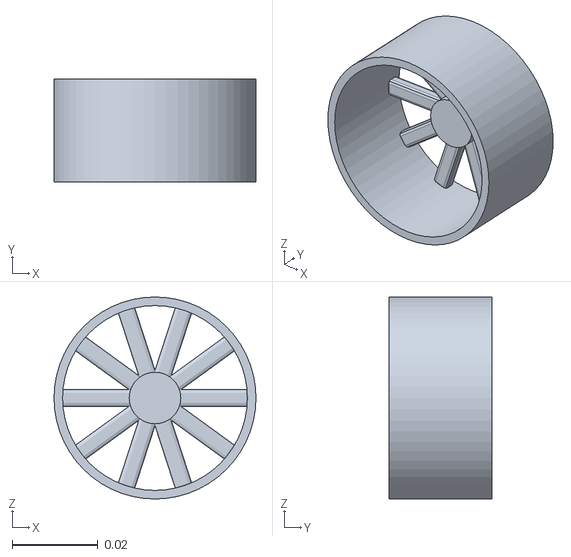
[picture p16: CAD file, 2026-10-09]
src/firefighter_description/meshes/left_wheel_visual_2.stl
0.047 x 0.024 x 0.047

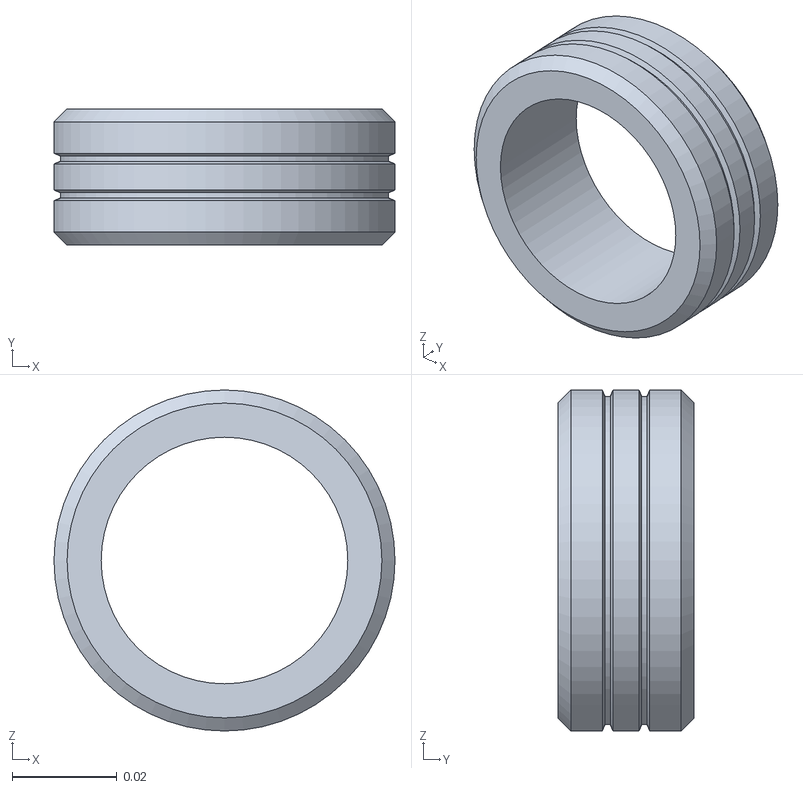
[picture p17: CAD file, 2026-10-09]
src/firefighter_description/meshes/right_wheel_visual_3.stl
0.065 x 0.026 x 0.065

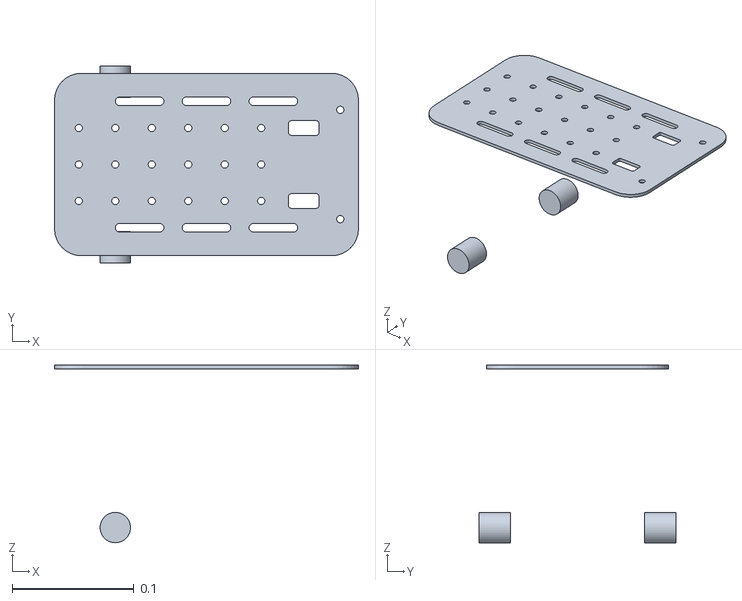
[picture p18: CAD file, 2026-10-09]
src/firefighter_description/meshes/base_link_visual_0.stl
0.25 x 0.162 x 0.146

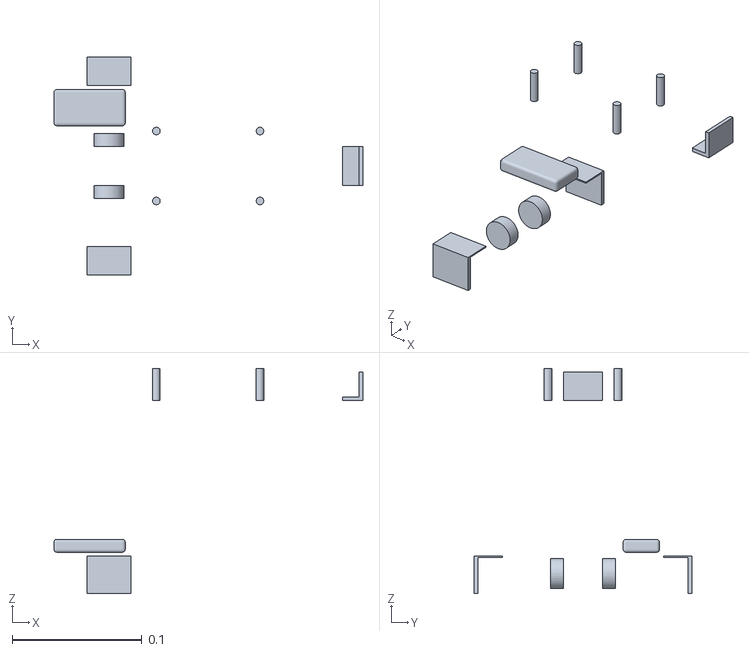
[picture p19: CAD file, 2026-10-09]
src/firefighter_description/meshes/base_link_visual_2.stl
0.238 x 0.168 x 0.174

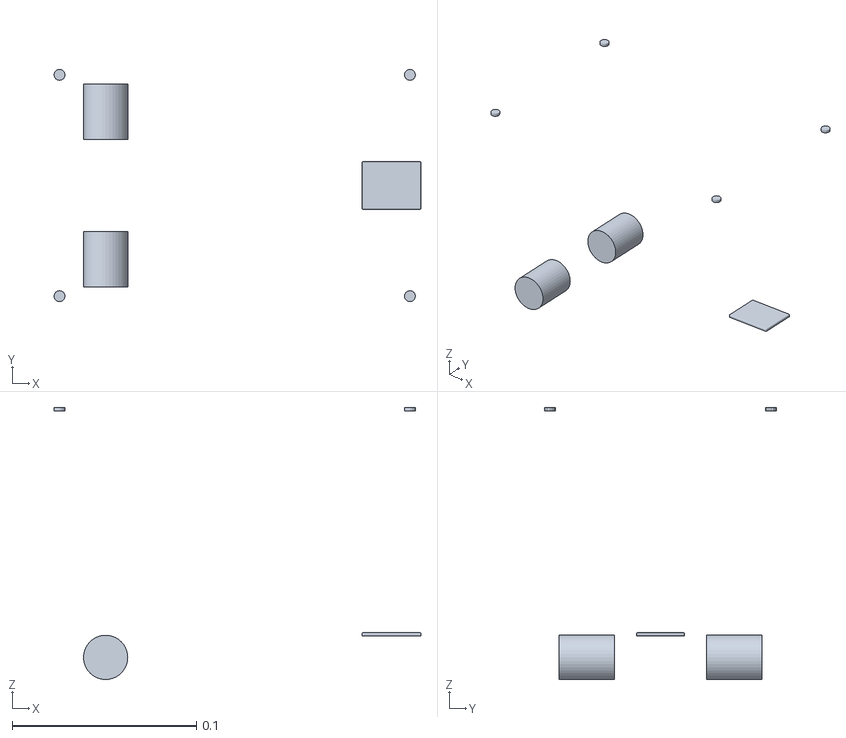
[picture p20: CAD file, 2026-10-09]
src/firefighter_description/meshes/base_link_visual_8.stl
0.199 x 0.126 x 0.148

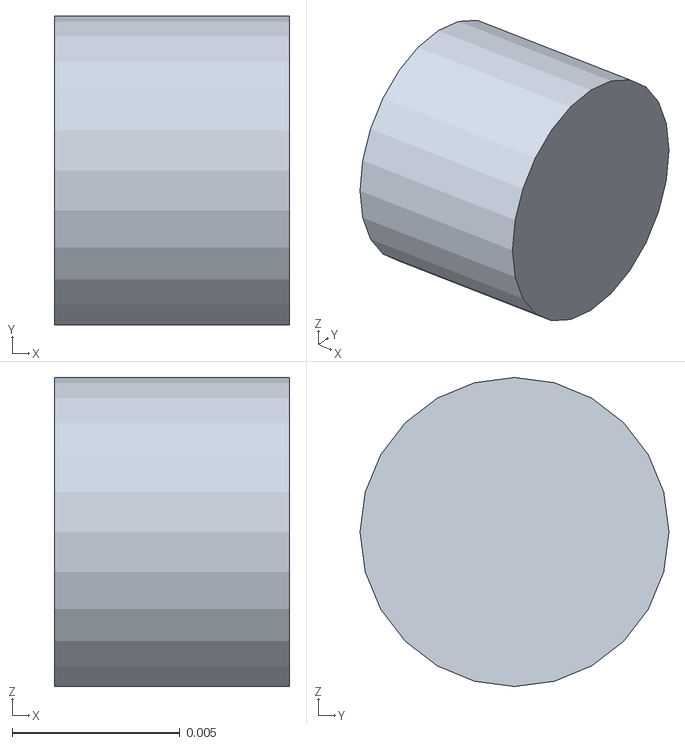
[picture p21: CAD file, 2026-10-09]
src/firefighter_description/meshes/thermal_camera_visual_2.stl
0.007 x 0.0092 x 0.0092

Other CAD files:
src/firefighter_description/meshes/right_wheel_visual_0.stl
src/firefighter_description/meshes/right_wheel_visual_4.stl
src/firefighter_description/meshes/right_wheel_visual_2.stl
src/firefighter_description/meshes/laser_visual_0.stl
model/firefighter.blend
src/firefighter_description/meshes/base_link_visual_3.stl
src/firefighter_description/meshes/base_link_visual_4.stl
src/firefighter_description/meshes/base_link_visual_5.stl
src/firefighter_description/meshes/base_link_visual_6.stl
src/firefighter_description/meshes/base_link_visual_7.stl
src/firefighter_description/meshes/caster_wheel_visual.stl
src/firefighter_description/meshes/left_wheel_visual_1.stl
src/firefighter_description/meshes/left_wheel_visual_3.stl
src/firefighter_description/meshes/right_wheel_visual_1.stl
src/firefighter_description/meshes/thermal_camera_visual_0.stl

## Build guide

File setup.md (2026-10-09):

# Firefighter Robot — Setup Guide
**Raspberry Pi 4 · Ubuntu 24.04 · ROS 2 Jazzy · Gazebo Harmonic · ESP32**

Two setups are covered:

- **[Simulation](#simulation-setup-laptoppc--wsl2)** — Gazebo + RViz on a Windows PC, inside WSL2.
- **[Real hardware](#real-hardware-setup-raspberry-pi-4)** — the Raspberry Pi 4 on the robot.

Day-to-day operation (launch arguments, mapping, the dashboard) is in
[`docs/runbook.md`](docs/runbook.md) and
[`src/firefighter_bringup/README.md`](src/firefighter_bringup/README.md); this
file only gets a machine to the point where those work.

---

## Simulation Setup (Laptop/PC — WSL2)

**Use WSL2, not a VMware/VirtualBox VM.** Gazebo Harmonic renders with Ogre2,
which flickers or crawls on a VM's virtual GPU. WSL2 passes the real GPU through
(WSLg), so Gazebo and RViz run at near-native speed with no workarounds.

### 1. Install WSL2 and Ubuntu 24.04

In an **administrator PowerShell** on Windows:

```powershell
wsl --install -d Ubuntu-24.04
```

Reboot if asked, then open **Ubuntu** from the Start menu. Everything below runs
inside that Ubuntu shell.

### 2. Install ROS 2 Jazzy Desktop and Gazebo

```bash
sudo apt update && sudo apt install -y locales software-properties-common curl
sudo locale-gen en_US en_US.UTF-8
sudo update-locale LC_ALL=en_US.UTF-8 LANG=en_US.UTF-8
export LANG=en_US.UTF-8

sudo add-apt-repository -y universe
sudo curl -sSL https://raw.githubusercontent.com/ros/rosdistro/master/ros.key -o /usr/share/keyrings/ros-archive-keyring.gpg
echo "deb [arch=$(dpkg --print-architecture) signed-by=/usr/share/keyrings/ros-archive-keyring.gpg] http://packages.ros.org/ros2/ubuntu $(. /etc/os-release && echo $UBUNTU_CODENAME) main" | sudo tee /etc/apt/sources.list.d/ros2.list > /dev/null

sudo apt update
sudo apt install -y ros-jazzy-desktop ros-dev-tools ros-jazzy-ros-gz cmake build-essential
```

```bash
echo "source /opt/ros/jazzy/setup.bash" >> ~/.bashrc
source ~/.bashrc
```

### 3. Clone the workspace

Clone **inside the Linux filesystem** (`~/`), not under `/mnt/c/`:

```bash
cd ~
git clone https://github.com/thechaelice/firefighter_ws.git
```

> **Do not copy or build the Windows checkout from `/mnt/c/...`.** Builds there
> are several times slower, and a Windows checkout can carry CRLF line endings
> that break `build.sh` (`$'\r': command not found`). A fresh clone in `~/` avoids
> both.

The launch files look for `config/` and `maps/` in `~/firefighter_ws`. If you
clone somewhere else, point them at it:

```bash
echo "export FIREFIGHTER_WS=/path/to/firefighter_ws" >> ~/.bashrc
```

### 4. Install workspace dependencies

```bash
cd ~/firefighter_ws
sudo rosdep init        # once per machine; "already initialized" is fine
rosdep update
rosdep install --from-paths src --ignore-src -r -y
```

That pulls in SLAM Toolbox, Nav2, `robot_localization`, `joint_state_publisher`,
`xacro` and the Gazebo bridge. If `rosdep` skips something, install the set by
hand:

```bash
sudo apt install -y \
  ros-jazzy-slam-toolbox ros-jazzy-navigation2 ros-jazzy-nav2-bringup \
  ros-jazzy-robot-localization ros-jazzy-joint-state-publisher ros-jazzy-xacro \
  ros-jazzy-ros-gz ros-jazzy-teleop-twist-keyboard
```

### 5. Build

`build.sh` defaults to one compiler job (it is tuned for the Pi). On a PC, raise it:

```bash
cd ~/firefighter_ws
JOBS=4 ./build.sh
source install/setup.bash
```

```bash
echo "source ~/firefighter_ws/install/setup.bash" >> ~/.bashrc
```

### 6. Run the simulation

```bash
ros2 launch firefighter_bringup sim.launch.py
```

This opens Gazebo with the `firehouse` world (three rooms, obstacles, a fire in
the far room), spawns the robot in the west room, and starts the same stack the
real robot runs — `rf2o`, the EKF, SLAM Toolbox, Nav2, the mission FSM — plus RViz.

| Variant | Command |
|---|---|
| Mapping only (no Nav2) | `ros2 launch firefighter_bringup sim.launch.py nav2_enabled:=false` |
| No RViz | `ros2 launch firefighter_bringup sim.launch.py rviz:=false` |
| No Gazebo window (lighter; RViz is the view) | `ros2 launch firefighter_bringup sim.launch.py gui:=false` |
| Different spawn pose | `ros2 launch firefighter_bringup sim.launch.py x:=2.5 y:=0.5 yaw:=1.57` |
| Different world | `ros2 launch firefighter_bringup sim.launch.py world:=/path/to/world.sdf` |

Drive it from a second terminal (click that terminal first so it has focus):

```bash
ros2 run teleop_twist_keyboard teleop_twist_keyboard
```

The bundled RViz config already has the robot model, `/scan` and `/map` displays
with **Fixed Frame** `map`; until SLAM starts publishing `map`, switch it to `odom`.

**What is and is not simulated**

| Real robot | In simulation |
|---|---|
| RPLIDAR A1 → `/scan` | Gazebo `gpu_lidar` → `/scan` |
| ESP32 bridge → `/wheel_odom`, takes `/cmd_vel` | Gazebo diff-drive → `/wheel_odom`, takes `/cmd_vel` |
| — | Gazebo → `/joint_states` (wheels turn in RViz) |
| MLX90641 reader → `/thermal/image`, `/flame_event` | Gazebo thermal camera → `/thermal/raw` → the same perception node |
| ESP-NOW beacons → `/beacon_event` | **not simulated** |

### 7. View the model only (no Gazebo)

```bash
ros2 launch firefighter_description description.launch.py
```

```bash
rviz2 -d $(ros2 pkg prefix firefighter_bringup)/share/firefighter_bringup/rviz/firefighter.rviz
```

Set **Fixed Frame** to `base_link`.

### 8. Verify Gazebo (optional)

```bash
gz sim -r shapes.sdf
```

### 9. Enable GPU rendering (optional)

WSL sometimes falls back to CPU rendering (`llvmpipe`), which makes Gazebo slow.

```bash
sudo apt install -y mesa-utils
glxinfo -B | grep "OpenGL renderer"
```

If that prints `llvmpipe`, force the Direct3D 12 driver. The last line names the
GPU vendor — change `NVIDIA` to `AMD` or `Intel` to match yours:

```bash
echo "export LIBGL_ALWAYS_SOFTWARE=false" >> ~/.bashrc
echo "export GALLIUM_DRIVER=d3d12" >> ~/.bashrc
echo "export MESA_D3D12_DEFAULT_ADAPTER_NAME=NVIDIA" >> ~/.bashrc
source ~/.bashrc
glxinfo -B | grep "OpenGL renderer"     # should now show D3D12 (<your GPU>)
```

### 10. Run the unit tests (optional)

The FSM, protocol codec and flame-detection tests are pure Python and need no
running ROS graph:

```bash
cd ~/firefighter_ws
python3 -m pytest tests
```

---

## Real Hardware Setup (Raspberry Pi 4)

### Part 1: Flash Ubuntu Server 24.04

With **Raspberry Pi Imager**: choose *Raspberry Pi 4* → *Other general-purpose
OS* → *Ubuntu* → **Ubuntu Server 24.04 LTS (64-bit)**. In *Edit Settings* set a
hostname, username and password, add Wi-Fi if needed, and enable **SSH** on the
Services tab. First boot takes several minutes.

```bash
ssh your-username@<hostname>.local     # or the Pi's IP address
```

Ubuntu Server does not ship an mDNS responder, so `<hostname>.local` only works
after:

```bash
sudo apt install -y avahi-daemon libnss-mdns
```

### Part 2: Install ROS 2 Jazzy (base)

```bash
sudo apt update && sudo apt install -y curl gnupg lsb-release ca-certificates software-properties-common
sudo add-apt-repository -y universe
sudo curl -sSL https://raw.githubusercontent.com/ros/rosdistro/master/ros.key -o /usr/share/keyrings/ros-archive-keyring.gpg
echo "deb [arch=$(dpkg --print-architecture) signed-by=/usr/share/keyrings/ros-archive-keyring.gpg] http://packages.ros.org/ros2/ubuntu $(. /etc/os-release && echo $UBUNTU_CODENAME) main" | sudo tee /etc/apt/sources.list.d/ros2.list > /dev/null

sudo apt update
sudo apt install -y ros-jazzy-ros-base ros-dev-tools cmake build-essential i2c-tools
echo "source /opt/ros/jazzy/setup.bash" >> ~/.bashrc && source ~/.bashrc
```

> **Do not install Gazebo (`ros-jazzy-ros-gz`) on the Pi.** It is only needed for
> simulation. `firefighter_bringup` lists it as a dependency for `sim.launch.py`,
> so on the Pi tell `rosdep` to skip it (Part 5).

> **"Unmet dependencies / held broken packages"** during the ROS install usually
> means Ubuntu's security repo upgraded `liblz4-1`, `libzstd1` or `zlib1g` past
> the version the ROS `-dev` packages pin. Check that `noble-updates` is in
> `/etc/apt/sources.list.d/ubuntu.sources`, run `sudo apt --fix-broken install`,
> and retry.

### Part 3: Harden the Pi against build lockups

A plain parallel `colcon build` can wedge this Pi's SD/MMC bus and take Wi-Fi
down with it (the full story is in the [README](README.md#1-build-the-workspace)).
`build.sh` avoids triggering it; these make the board robust regardless:

```bash
sudo apt install -y zram-tools earlyoom
# set ALGO=zstd and PERCENT=50 in /etc/default/zramswap, then:
sudo systemctl restart zramswap
```

Prefer Ethernet over Wi-Fi, and a USB SSD over the SD card, if you can.

### Part 4: Enable the buses

The Pi talks to three devices:

| Device | Bus | Appears as |
|---|---|---|
| RPLIDAR A1 | USB serial adapter | `/dev/ttyUSB0` |
| Mobility ESP32 | UART on GPIO14 (TXD) / GPIO15 (RXD), 115200 8N1 | `/dev/ttyAMA0` |
| MLX90641 thermal camera | I²C1 on GPIO2 (SDA) / GPIO3 (SCL), address `0x33` | `/dev/i2c-1` |

Wiring tables: [`firmware/README.md`](firmware/README.md#5-pi--esp32-uart-link-option-a--active)
for the UART, [`docs/thermal-camera.md`](docs/thermal-camera.md) for the camera.

**1. Device-tree settings**

```bash
sudo tee -a /boot/firmware/config.txt <<'EOF'
dtparam=i2c_arm=on
enable_uart=1
dtoverlay=miniuart-bt
EOF
```

`miniuart-bt` moves Bluetooth to the mini-UART so the full PL011 UART
(`/dev/ttyAMA0`) is free on GPIO14/15.

**2. Take the serial console off that UART**

Edit `/boot/firmware/cmdline.txt` and delete the `console=serial0,115200` token
(leave the rest of the line intact), then:

```bash
sudo systemctl disable --now serial-getty@ttyAMA0.service
sudo systemctl mask serial-getty@ttyAMA0.service
```

**3. Permissions**

```bash
sudo usermod -aG dialout,i2c $USER
sudo reboot
```

**4. Verify after the reboot**

```bash
groups                         # includes dialout and i2c
ls -l /dev/ttyUSB0 /dev/ttyAMA0
i2cdetect -y 1                 # 0x33 is the thermal camera
```

### Part 5: Clone, install dependencies, build

```bash
cd ~
git clone https://github.com/thechaelice/firefighter_ws.git
cd ~/firefighter_ws

sudo rosdep init && rosdep update
rosdep install --from-paths src --ignore-src -r -y \
  --skip-keys "ros_gz_sim ros_gz_bridge"
```

Build with the wrapper — **never a bare `colcon build` on the Pi**:

```bash
./build.sh
source install/setup.bash
echo "source ~/firefighter_ws/install/setup.bash" >> ~/.bashrc
```

Then build the thermal camera reader (clones the Melexis vendor library):

```bash
bash scripts/thermal/build.sh
```

### Part 6: Flash the ESP32s

The mobility controller and the fire beacons are Arduino sketches under
[`firmware/`](firmware/). Board settings, pinouts and beacon MAC pairing are in
[`firmware/README.md`](firmware/README.md#4-flashing--setup-instructions).

`WHEEL_RADIUS_M` and `ENCODER_TICKS_PER_REV` in `robot_mobility.ino` **must match**
`wheel_radius_m` / `ticks_per_rev` in
[`src/firefighter_bridge/config/bridge.yaml`](src/firefighter_bridge/config/bridge.yaml),
and the wheel radius and track width there must match
[`firefighter.gazebo.xacro`](src/firefighter_description/urdf/firefighter.gazebo.xacro).

### Part 7: Run the robot

Check the pieces one at a time first:

```bash
ros2 launch sllidar_ros2 sllidar_a1_launch.py serial_port:=/dev/ttyUSB0
ros2 topic hz /scan                      # ~7-10 Hz
```

```bash
python3 scripts/motor_test.py --linear 0.10 --duration 2    # robot on blocks!
```

Then the whole stack:

```bash
ros2 launch firefighter_bringup bringup.launch.py rviz:=false
```

The Pi has no display, so leave RViz off there. Watch it from a browser with the
dashboard (`python3 scripts/robot_dashboard.py`, then `http://<pi-ip>:8080/`), or
run RViz on the PC — see below.

### Part 8: RViz on the PC, robot on the Pi

ROS 2 discovers nodes over the LAN by multicast, so a PC on the same network
sees the Pi's topics once both use the same domain ID (default `0`):

```bash
rviz2 -d $(ros2 pkg prefix firefighter_bringup)/share/firefighter_bringup/rviz/firefighter.rviz
```

From **WSL2** this needs mirrored networking, because the default NAT hides WSL
from the LAN. Put this in `C:\Users\<you>\.wslconfig` on Windows, then run
`wsl --shutdown` and reopen Ubuntu:

```ini
[wsl2]
networkingMode=mirrored
```

Phone hotspots and some routers drop multicast between clients; if `ros2 topic
list` on the PC shows nothing from the Pi while `ping <pi-ip>` works, that is why.

---

## Troubleshooting

### Build

| Symptom | Fix |
|---|---|
| `./build.sh: $'\r': command not found` | The checkout has Windows line endings. Clone fresh inside WSL/Linux instead of using a `/mnt/c` copy. |
| `colcon: command not found` | `sudo apt install python3-colcon-common-extensions` (included in `ros-dev-tools`). |
| `package 'slam_toolbox' not found` (or `nav2_bringup`, `robot_localization`, `joint_state_publisher`) at launch | Dependencies not installed — rerun the `rosdep install` step, or the explicit `apt install` list in Simulation §4. |
| Pi drops off SSH during a build | A parallel build wedged the SD/MMC bus. Power-cycle, then only ever use `./build.sh` (Part 3). |
| Launch cannot find `config/nav2_params.yaml` | The workspace is not at `~/firefighter_ws`; set `FIREFIGHTER_WS`. |

### Simulation

| Symptom | Fix |
|---|---|
| Gazebo is very slow | Software rendering — follow Simulation §9. |
| `/scan` is well under 8 Hz, map appears late | The PC cannot simulate in real time, and sensor rates follow simulation time. Check `gz topic -e -n 1 -t /stats` (`real_time_factor` should be near 1). Launch with `gui:=false`, or `nav2_enabled:=false` while mapping, and close other heavy programs. |
| Gazebo window opens but the robot is missing | Check the launch terminal for a `create` error; the robot is spawned from `/robot_description`, so `robot_state_publisher` must be up. |
| Robot appears without meshes | `GZ_SIM_RESOURCE_PATH` was overridden; launch through `sim.launch.py`, which sets it. |
| RViz shows "No transform from [laser] to [map]" for the first seconds | Normal — SLAM and Nav2 start `startup_delay` seconds (8 by default) after Gazebo. Raise it on a slow machine: `startup_delay:=15.0`. |
| Robot ignores teleop | Nav2 or the mission node is also publishing `/cmd_vel`. Launch with `nav2_enabled:=false`. |
| `no thermal frames for 5.x s` once at startup | Harmless — the simulated frame source takes a few seconds to connect. It is only a problem if `/thermal/image` never appears. |
| Thermal image is uniformly cold | The fire is not in view: the camera has a 55° lens and looks straight ahead. Drive into the east room and face the orange cylinder. |
| Everything is frozen at t=0 | `/clock` is not bridged — check `ros2 topic hz /clock`. |

### Robot

| Symptom | Fix |
|---|---|
| No `/dev/ttyUSB0` | Check the LiDAR's USB cable and power; `lsusb` should list a CP210x/CH340 device. |
| `/scan` is silent | Start the motor: `ros2 service call /start_motor std_srvs/srv/Empty "{}"`. |
| `Permission denied: '/dev/ttyAMA0'` or `/dev/ttyUSB0` | Not in `dialout` yet — `sudo usermod -aG dialout $USER`, then log out and back in. |
| Bridge reports the ESP32 link is down | Serial console still owns the UART (Part 4, step 2), TX/RX swapped, or the ESP32 is on UART1 instead of UART2 (GPIO16/17). |
| `i2cdetect -y 1` shows nothing at `0x33` | `dtparam=i2c_arm=on` missing or not rebooted; otherwise check SDA/SCL wiring. |
| Thermal frames are garbage | The sensor is an MLX9064**1**, not an MLX90640 — use the reader in `scripts/thermal/`, see [`docs/thermal-camera.md`](docs/thermal-camera.md). |
| TF tree unstable / `base_link` has two parents | Something else is publishing a transform bringup already owns — see the TF-ownership section of the [bringup README](src/firefighter_bringup/README.md#tf-ownership-rep-105). |

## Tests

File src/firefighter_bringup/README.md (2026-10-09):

# firefighter_bringup

One launch file for the whole robot.

```bash
cd ~/firefighter_ws && ./build.sh && source install/setup.bash
ros2 launch firefighter_bringup bringup.launch.py
```

## What comes up

| Stage | Node | Produces |
|---|---|---|
| model | `firefighter_description` (`robot_state_publisher`) | `/robot_description`, **`base_link → laser`**, **`base_link → thermal_camera`** |
| sensing | `sllidar_ros2` | `/scan` |
| odometry | `rf2o_laser_odometry` | `/odom_rf2o` |
| odometry | `robot_localization` `ekf_filter_node` | `/odometry/filtered`, **`odom → base_link`** |
| robot | `firefighter_bridge` | `/wheel_odom`, `/beacon_event`, `/battery`, `/diagnostics` |
| robot | `firefighter_perception` | `/thermal/image`, `/flame_event` |
| autonomy | `slam_toolbox` | **`map → odom`** |
| autonomy | `nav2_bringup` | `navigate_to_pose` action |
| autonomy | `firefighter_mission` | mission FSM |
| operator | `rviz2` | `rviz/firefighter.rviz` |

## TF ownership (REP-105)

Exactly one node publishes each transform - this is the thing that most often
goes wrong:

```
map ──(slam_toolbox)──> odom ──(robot_localization EKF)──> base_link ──(robot_state_publisher)──> laser
                                                                    └──(robot_state_publisher)──> thermal_camera
```

* The sensor mounts come from the URDF in `firefighter_description`
  (`urdf/firefighter.urdf.xacro`, exported from `model/firefighter.blend`). To move
  a sensor, change the model and re-export - there are no mount launch arguments.

* `rf2o` has **`publish_tf: false`** (`config/rf2o.yaml`). It feeds `odom → base_link`
  into the EKF, it does not broadcast it.
* The bridge publishes `/wheel_odom` with **`publish_tf: false`** for the same reason.
* The EKF fuses `/odom_rf2o` (pose) with `/wheel_odom` (velocity) and owns the
  `odom → base_link` broadcast.

## Launch arguments

| Argument | Default | Meaning |
|---|---|---|
| `serial_port` | `/dev/ttyUSB0` | LiDAR |
| `bridge_port` | `/dev/ttyAMA0` | UART to the mobility ESP32 |
| `config_dir` | `$FIREFIGHTER_WS/config` | upstream param files |
| `slam` | `true` | `true` = SLAM Toolbox; `false` = AMCL on `map` |
| `map` | `$FIREFIGHTER_WS/maps/map.yaml` | used when `slam:=false` |
| `nav2_enabled` | `true` | set `false` to bring up mapping only |
| `rviz` | `true` | |
| `startup_delay` | `3.0` | wait before SLAM/Nav2 so TF and `/scan` exist |
| `thermal_reader_path` | `$FIREFIGHTER_WS/scripts/thermal/mlx90641_frames` | MLX90641 reader |
| `hardware` | `true` | `false` skips the LiDAR and ESP32 bridge (simulation) |
| `model` | `firefighter_description/urdf/firefighter.urdf.xacro` | XACRO published on `/robot_description` |

`FIREFIGHTER_WS` defaults to `~/firefighter_ws`; set it if the workspace moves.
The sensor positions in the model are **estimated from photos** - measure the robot.

## Simulation (Gazebo Harmonic, WSL2)

`sim.launch.py` starts Gazebo with `firefighter_description/worlds/firehouse.sdf`
(three rooms, obstacles, a fire in the far room), spawns the robot and runs this
same bringup with `hardware:=false`. Gazebo publishes what the hardware would:
`/scan`, `/wheel_odom` and `/joint_states`, and drives the wheels from `/cmd_vel`.

One-off setup in WSL2 Ubuntu 24.04 with ROS 2 Jazzy (`ros-jazzy-desktop`,
`ros-jazzy-ros-gz`), with the workspace cloned to `~/firefighter_ws`:

```bash
cd ~/firefighter_ws
rosdep install --from-paths src --ignore-src -r -y   # slam_toolbox, nav2, robot_localization, ...
JOBS=4 ./build.sh && source install/setup.bash
```

```bash
ros2 launch firefighter_bringup sim.launch.py                      # Gazebo + SLAM + Nav2 + RViz
ros2 launch firefighter_bringup sim.launch.py nav2_enabled:=false  # mapping only
ros2 run teleop_twist_keyboard teleop_twist_keyboard               # drive it (second terminal)
```

To look at the model alone in RViz, without Gazebo:

```bash
ros2 launch firefighter_description description.launch.py
rviz2 -d $(ros2 pkg prefix firefighter_bringup)/share/firefighter_bringup/rviz/firefighter.rviz
```

The thermal camera is simulated too: a 16×12 Gazebo thermal sensor publishes
`/thermal/raw`, and `firefighter_perception`'s `sim_thermal_frames` feeds it to the
unmodified perception node in place of the MLX90641 reader. The fire in the east
room reads about 326 °C against a 15 °C background, so `/flame_event` fires when
the robot faces it.

## Mapping then localizing

```bash
# 1. build a map (drive around with teleop; Nav2 holds the map frame)
ros2 launch firefighter_bringup bringup.launch.py
ros2 run nav2_map_server map_saver_cli -f ~/firefighter_ws/maps/map

# 2. later, localize against it instead of mapping
ros2 launch firefighter_bringup bringup.launch.py slam:=false
```

## Caveats

`config/slam_toolbox.yaml` and `config/nav2_params.yaml` are the stock Jazzy
defaults with only frames, odom source and robot radius adapted. **Nothing is
tuned** - expect to revisit speeds, accelerations, inflation and the robot radius
once the robot actually drives.

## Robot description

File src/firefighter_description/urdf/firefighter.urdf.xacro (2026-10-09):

<?xml version="1.0"?>
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
<robot xmlns:xacro="http://ros.org/wiki/xacro" name="firefighter">
  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
  <xacro:property name="aluminium" value="0.78 0.79 0.8 1" />
  <xacro:property name="battery" value="0.07 0.09 0.2 1" />
  <xacro:property name="black_plastic" value="0.03 0.03 0.035 1" />
  <xacro:property name="brass" value="0.72 0.56 0.22 1" />
  <xacro:property name="clear_plastic" value="0.8 0.88 0.92 0.45" />
  <xacro:property name="latch_blue" value="0.08 0.16 0.7 1" />
  <xacro:property name="lens" value="0.02 0.02 0.03 1" />
  <xacro:property name="nylon" value="0.2 0.2 0.21 1" />
  <xacro:property name="pcb_blue" value="0.03 0.16 0.5 1" />
  <xacro:property name="pcb_green" value="0.03 0.32 0.1 1" />
  <xacro:property name="pcb_red" value="0.55 0.04 0.04 1" />
  <xacro:property name="rim_blue" value="0.06 0.42 0.72 1" />
  <xacro:property name="rubber" value="0.012 0.012 0.012 1" />
  <xacro:property name="steel" value="0.55 0.56 0.58 1" />
  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
  <link name="base_link">
    <inertial>
      <origin xyz="0.07 0 0.0495" rpy="0 0 0" />
      <mass value="0.9" />
      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
    </inertial>
    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
  </link>
  <link name="caster_swivel">
    <inertial>
      <origin xyz="-0.006 0 -0.01975" rpy="0 0 0" />
      <mass value="0.015" />
      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
    </inertial>
    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
  </link>
  <link name="caster_wheel">
    <inertial>
      <origin xyz="0 1.396984e-09 0" rpy="0 0 0" />
      <mass value="0.008" />
      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
    </inertial>
    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
  </link>
  <link name="laser">
    <inertial>
      <origin xyz="0 0 -0.01" rpy="0 0 0" />
      <mass value="0.17" />
      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
    </inertial>
    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
  </link>
  <link name="left_wheel">
    <inertial>
      <origin xyz="0 0 0" rpy="-1.570796 0 0" />
      <mass value="0.04" />
      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
    </inertial>
    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
  </link>
  <link name="right_wheel">
    <inertial>
      <origin xyz="0 0 0" rpy="1.570796 0 0" />
      <mass value="0.04" />
      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
    </inertial>
    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
  </link>
  <link name="thermal_camera">
    <inertial>
      <origin xyz="-0.0045 0 0" rpy="0 0 0" />
      <mass value="0.005" />
      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
    </inertial>
    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
  </link>
  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
  <joint name="caster_swivel_joint" type="continuous">
    <origin xyz="0.155 0 0.0115" rpy="0 0 0" />
    <parent link="base_link" />
    <child link="caster_swivel" />
    <axis xyz="0 0 1" />
    <limit effort="1" velocity="100" lower="0" upper="0" />
  </joint>
  <joint name="caster_wheel_joint" type="continuous">
    <origin xyz="-0.012 0 -0.0315" rpy="0 0 0" />
    <parent link="caster_swivel" />
    <child link="caster_wheel" />
    <axis xyz="0 1 0" />
    <limit effort="1" velocity="100" lower="0" upper="0" />
  </joint>
  <joint name="laser_joint" type="fixed">
    <origin xyz="0.09 0 0.191" rpy="0 0 0" />
    <parent link="base_link" />
    <child link="laser" />
  </joint>
  <joint name="left_wheel_joint" type="continuous">
    <origin xyz="0 0.1 0" rpy="0 0 0" />
    <parent link="base_link" />
    <child link="left_wheel" />
    <axis xyz="0 1 0" />
    <limit effort="0.5" velocity="20" lower="0" upper="0" />
  </joint>
  <joint name="right_wheel_joint" type="continuous">
    <origin xyz="0 -0.1 0" rpy="0 0 0" />
    <parent link="base_link" />
    <child link="right_wheel" />
    <axis xyz="0 1 0" />
    <limit effort="0.5" velocity="20" lower="0" upper="0" />
  </joint>
  <joint name="thermal_camera_joint" type="fixed">
    <origin xyz="0.2046 0 0.1465" rpy="0 0 0" />
    <parent link="base_link" />
    <child link="thermal_camera" />
  </joint>
</robot>

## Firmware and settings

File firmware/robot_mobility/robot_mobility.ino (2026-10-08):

// ============================================================
// FIREFIGHTING ROBOT - MOBILITY / GATEWAY ESP32
// ESP32 Arduino Core 2.0.x
//
// ROLE
//   * Low-level motor + encoder controller, with closed-loop
//     (feedforward + PI) wheel speed control on SET_TWIST
//   * UART gateway between the Raspberry Pi (ROS 2) and the
//     wireless fire beacon (ESP-NOW)
//
// TOPOLOGY
//   Beacon --ESP-NOW--> [this ESP32] --UART2--> Raspberry Pi
//
// MOTION OWNERSHIP  (see MOTION_OWNER_IS_PI below)
//   1 -> the Pi sends SET_TWIST frames and owns the motion.
//        Beacon events are only forwarded to the Pi.
//   0 -> fallback: the ESP32 runs its original fixed
//        forward / right / left maneuver when the beacon reports
//        two consecutive FIRE + SMOKE packets.
//
// SAFETY
//   * Watchdog: in Pi mode the motors stop if no valid Pi frame
//     arrives for PI_TIMEOUT_MS.
//   * MSG_ESTOP latches a stop until MSG_RESET_FAULT arrives.
//
// !! NON-BLOCKING: the control path uses millis() only.
//    There is not a single delay() call in loop() or any of the
//    motion / sequence code.
// ============================================================

#include <WiFi.h>
#include <esp_now.h>
#include <esp_wifi.h>

#include "firefighter_protocol.h"


// ============================================================
// COMPILE-TIME CONFIGURATION
// ============================================================

// ---- Who owns motion ---------------------------------------
// 1 = Raspberry Pi (normal, Option A)
// 0 = on-board fixed maneuver (legacy fallback)
#define MOTION_OWNER_IS_PI 1

// ---- Debug output (USB serial, UART0) ----------------------
// Set DEBUG_ENABLED to 0 to compile out all debug output.
#define DEBUG_ENABLED 1

class NullStream : public Print {
 public:
  void   begin(unsigned long) {}
  size_t write(uint8_t) override { return 1; }
  size_t write(const uint8_t*, size_t n) override { return n; }
};
static NullStream DBG_null;

#if DEBUG_ENABLED
  #define DBG Serial       // USB-serial debug stream
#else
  #define DBG DBG_null     // silent sink
#endif


// ============================================================
// UART LINK TO THE RASPBERRY PI   (UART2)
// ------------------------------------------------------------
// ESP32 GPIO16 (RX) <- Pi GPIO14 (TXD)
// ESP32 GPIO17 (TX) -> Pi GPIO15 (RXD)
// GND <-> GND   (3.3 V logic on both sides, no shifter)
//
// Do NOT use UART1 (GPIO9/10): those pins are wired to the SPI
// flash on WROOM modules.
// ============================================================

const int UART_RX_PIN = 16;
const int UART_TX_PIN = 17;
const long UART_BAUD  = 115200;

// (not named PI: Arduino.h #defines PI as 3.14159...)
HardwareSerial& PiLink = Serial2;   // the UART link to the Raspberry Pi


// ============================================================
// TIMING (all non-blocking, millis() based)
// ============================================================

const uint32_t PI_TIMEOUT_MS   = 500;   // no valid Pi frame -> stop
const uint32_t ODOM_PERIOD_MS  = 20;    // 50 Hz wheel odometry
const uint32_t STATUS_PERIOD_MS = 200;  // 5 Hz status
const uint32_t HB_PERIOD_MS    = 1000;  // 1 Hz ESP32 heartbeat

// Fallback maneuver timings (match the legacy firmware)
const uint32_t FB_FWD_MS   = 5000;
const uint32_t FB_RIGHT_MS = 3000;
const uint32_t FB_LEFT_MS  = 5000;
const uint32_t FB_PAUSE_MS = 500;


// ============================================================
// MOTOR DRIVER PINS
// ============================================================

// Motor 1 (left)
const int ENA = 14;
const int IN1 = 27;
const int IN2 = 26;

// Motor 2 (right)
const int IN3 = 25;
const int IN4 = 33;
const int ENB = 32;


// ============================================================
// ENCODER PINS
// ============================================================

// Motor 1 encoder
const int M1_ENC_A = 18;   // Green
const int M1_ENC_B = 19;   // Blue

// Motor 2 encoder
const int M2_ENC_A = 22;   // Green
const int M2_ENC_B = 23;   // Blue

// Flip these if a wheel counts backwards on your wiring
const bool M1_ENC_INVERT = false;
const bool M2_ENC_INVERT = false;


// ============================================================
// PWM SETTINGS (ESP32 Arduino Core 2.0.x and 3.x)
// ============================================================

const int PWM_CHANNEL_A  = 0;
const int PWM_CHANNEL_B  = 1;
const int PWM_FREQ       = 5000;
const int PWM_RESOLUTION = 8;     // 0..255

// Core 3.x dropped ledcSetup()/ledcAttachPin(); ledcWrite() now takes
// the PIN instead of the channel. PWM_A / PWM_B are whatever ledcWrite()
// expects on the core being built against.
#if ESP_ARDUINO_VERSION_MAJOR >= 3
  #define PWM_A ENA
  #define PWM_B ENB
#else
  #define PWM_A PWM_CHANNEL_A
  #define PWM_B PWM_CHANNEL_B
#endif

// Legacy open-loop speed used by the fallback maneuver (~71%)
const int MOTOR_SPEED = 180;

// Below this magnitude the motor is off (avoids buzzing at low duty)
const int MOTOR_DEADBAND = 8;


// ============================================================
// DRIVE GEOMETRY  (used to turn SET_TWIST into wheel speeds)
// Adjust to the real robot.
// ============================================================

const float TRACK_WIDTH_M  = 0.20f;   // distance between wheels (m)
const float MAX_WHEEL_MPS  = 0.50f;   // fastest wheel speed a command may ask for
const float MIN_WHEEL_MPS  = 0.01f;   // commands below this are treated as stop

// Wheel + encoder (MUST MATCH wheel_radius_m / ticks_per_rev in the
// bridge's config/bridge.yaml, or the two sides disagree about speed).
const float WHEEL_RADIUS_M        = 0.0325f;
const long  ENCODER_TICKS_PER_REV = 1440;     // 360 CPR x4 quadrature
const float METERS_PER_TICK =
    (2.0f * 3.14159265f * WHEEL_RADIUS_M) / (float)ENCODER_TICKS_PER_REV;

// Lowest PWM at which the wheels reliably turn under load. Used as the
// feedforward starting point; the speed loop corrects from there. CALIBRATE on
// the robot (scripts/motor_test.py).
const int MOTOR_MIN_MOVE_PWM = 120;


// ============================================================
// CLOSED-LOOP WHEEL SPEED CONTROL
//
// Each wheel runs feedforward + PI on its encoder speed, so a
// SET_TWIST of 0.05 m/s gives 0.05 m/s rather than whatever a fixed
// PWM happens to produce. Gains are starting values - TUNE on the
// robot: raise VEL_KI if slow commands take long to start, lower
// VEL_KP / VEL_KI if the wheels surge or oscillate.
//
// REQUIRES each encoder to count UP when its wheel drives the robot
// forward. If one counts down, flip M1_ENC_INVERT / M2_ENC_INVERT.
// A wheel whose encoder disagrees with its motor (wrong sign, or no
// counts at all) trips encoderFault: both wheels drop back to
// open-loop feedforward until MSG_RESET_FAULT, so a bad encoder can
// never wind the loop up to full speed.
//
// Set VELOCITY_CONTROL_ENABLED to 0 to run open-loop feedforward only.
// ============================================================

#define VELOCITY_CONTROL_ENABLED 1

const uint32_t VEL_PERIOD_MS    = 20;       // 50 Hz control loop
const float    VEL_KP           = 150.0f;   // PWM per (m/s) of speed error
const float    VEL_KI           = 1500.0f;  // PWM per (m/s) of error, per second
const float    VEL_FILTER_ALPHA = 0.5f;     // low-pass on measured speed (1 = none)

const int      ENC_FAULT_PWM     = 150;     // "driving hard" threshold
const float    ENC_FAULT_MIN_MPS = 0.02f;   // slower than this counts as not moving
const uint32_t ENC_FAULT_MS      = 700;     // how long the disagreement must last


// ============================================================
// ESP-NOW MESSAGE (MUST MATCH THE BEACON EXACTLY)
// ============================================================

typedef struct struct_message {
  int  messageNumber;
  bool fireDetected;
  bool smokeDetected;
} struct_message;

struct_message incomingData;

// Fallback trigger requires this many consecutive detections
const int REQUIRED_DETECTIONS = 2;

// ---- Beacon pairing ----------------------------------------
// The beacon does not hardcode this board's MAC. It broadcasts a
// PAIR_REQUEST; we answer with a broadcast PAIR_REPLY and the beacon
// reads our MAC from the reply's source address.
// (MUST MATCH beacon.ino EXACTLY. Its size differs from
// struct_message, so the two never get confused.)
const uint8_t BROADCAST_MAC[6] = {0xFF, 0xFF, 0xFF, 0xFF, 0xFF, 0xFF};

const uint32_t PAIR_MAGIC   = 0x46465052;   // "FFPR"
const uint8_t  PAIR_REQUEST = 1;            // beacon   -> broadcast
const uint8_t  PAIR_REPLY   = 2;            // mobility -> broadcast

typedef struct __attribute__((packed)) pair_message {
  uint32_t magic;
  uint8_t  type;
} pair_message;

// Set in the ESP-NOW callback, answered from loop()
volatile bool pairReplyPending = false;


// ============================================================
// STATE
// ============================================================

ff::Parser parser;
ff::Frame  frame;

volatile long motor1_encoder_count = 0;
volatile long motor2_encoder_count = 0;

// Last commanded motor magnitudes (for the MOVING status flag)
int motorCmdA = 0;
int motorCmdB = 0;

// Per-wheel speed controller. Declared here, before the first function,
// for the same prototype-hoisting reason as FbState below.
struct WheelCtl {
  float    target;      // commanded speed, m/s (+ = robot forward)
  float    measured;    // filtered encoder speed, m/s
  float    integral;    // PI integral term, in PWM counts
  long     prevTicks;   // encoder count at the previous control step
  uint32_t badSinceMs;  // when encoder and motor started to disagree (0 = fine)
};

WheelCtl wheelL = {0.0f, 0.0f, 0.0f, 0, 0};
WheelCtl wheelR = {0.0f, 0.0f, 0.0f, 0, 0};

bool     velControlActive = false;   // true while SET_TWIST owns the motors
bool     encoderFault     = false;   // latched: speed loop disabled, open-loop only
uint32_t lastVelMs        = 0;

// Watchdog / faults
uint32_t lastPiFrameMs = 0;
bool     linkFault     = false;   // Pi silent
bool     estop         = false;   // latched by MSG_ESTOP

// Periodic bookkeeping
uint32_t lastOdomMs   = 0;
uint32_t lastStatusMs = 0;
uint32_t lastHbMs     = 0;
uint16_t hbSeq        = 0;

// Fallback detection
volatile int consecutiveDetectionCount = 0;

// Fallback maneuver states. Declared here, before the first function,
// because the Arduino IDE hoists auto-generated prototypes (including
// fbEnter(FbState)) to just above the first function in the sketch.
enum FbState { FB_IDLE, FB_FWD, FB_PAUSE1, FB_RIGHT, FB_PAUSE2, FB_LEFT, FB_DONE };


// ============================================================
// LOW-LEVEL MOTOR CONTROL
//
// setMotor() takes a SIGNED speed where positive = that wheel
// drives the robot FORWARD. Motor 2 is mounted as a mirror
// image, so its direction pins are inverted here - this is the
// mirroring that the old moveForward()/turnRight() helpers
// encoded by hand.
// ============================================================

void setMotor(uint8_t motor, int signedSpeed) {
  int mag = abs(signedSpeed);
  if (mag < MOTOR_DEADBAND) mag = 0;

  if (motor == 1) {
    digitalWrite(IN1, signedSpeed >= 0 ? HIGH : LOW);
    digitalWrite(IN2, signedSpeed >= 0 ? LOW  : HIGH);
    ledcWrite(PWM_A, mag);
    motorCmdA = mag;
  } else {
    // Motor 2 is physically mirrored
    digitalWrite(IN3, signedSpeed >= 0 ? LOW  : HIGH);
    digitalWrite(IN4, signedSpeed >= 0 ? HIGH : LOW);
    ledcWrite(PWM_B, mag);
    motorCmdB = mag;
  }
}

void stopMotors() {
  digitalWrite(IN1, LOW);
  digitalWrite(IN2, LOW);
  digitalWrite(IN3, LOW);
  digitalWrite(IN4, LOW);
  ledcWrite(PWM_A, 0);
  ledcWrite(PWM_B, 0);
  motorCmdA = 0;
  motorCmdB = 0;

  // Also release the speed loop, or its next step would re-energise the motors.
  velControlActive = false;
  wheelL.target = wheelR.target = 0.0f;
  wheelL.integral = wheelR.integral = 0.0f;
}

// Open-loop feedforward: wheel speed (m/s) -> signed PWM. The motors do
// not turn below MOTOR_MIN_MOVE_PWM, so a non-zero speed is mapped onto
// [MOTOR_MIN_MOVE_PWM .. 255] instead of [0 .. 255]; otherwise slow
// commands (search spin, Nav2 fine positioning) only make them hum.
int wheelSpeedToPwm(float v) {
  float mag = fabsf(v);
  if (mag < MIN_WHEEL_MPS) return 0;
  if (mag > MAX_WHEEL_MPS) mag = MAX_WHEEL_MPS;
  float pwm = MOTOR_MIN_MOVE_PWM +
              (mag / MAX_WHEEL_MPS) * (255.0f - MOTOR_MIN_MOVE_PWM);
  return v >= 0.0f ? (int)pwm : -(int)pwm;
}

// Hand the wheels a new speed target (m/s). The motors are driven by
// updateVelocityControl(), at most VEL_PERIOD_MS later.
void setWheelTargets(float vL, float vR) {
  wheelL.target = constrain(vL, -MAX_WHEEL_MPS, MAX_WHEEL_MPS);
  wheelR.target = constrain(vR, -MAX_WHEEL_MPS, MAX_WHEEL_MPS);
  velControlActive = true;
}

// One control step for one wheel: update its measured speed and return
// the signed PWM to apply.
int wheelControlStep(WheelCtl& w, long ticks, float dt, uint32_t now) {
  float raw = (float)(ticks - w.prevTicks) * METERS_PER_TICK / dt;
  w.prevTicks = ticks;
  w.measured += VEL_FILTER_ALPHA * (raw - w.measured);

  // A zero target means stop now, not "regulate to zero".
  if (fabsf(w.target) < MIN_WHEEL_MPS) {
    w.integral   = 0.0f;
    w.badSinceMs = 0;
    return 0;
  }

  int ff = wheelSpeedToPwm(w.target);
  if (!VELOCITY_CONTROL_ENABLED || encoderFault) return ff;

  float err = w.target - w.measured;
  float out = (float)ff + VEL_KP * err + w.integral;

  // Only ever drive in the commanded direction: the loop may ease off
  // to zero, but it does not reverse the motor to brake.
  float lo = (w.target > 0.0f) ? 0.0f : -255.0f;
  float hi = (w.target > 0.0f) ? 255.0f : 0.0f;
  bool atHi = out >= hi;
  bool atLo = out <= lo;
  out = constrain(out, lo, hi);

  // Anti-windup: stop integrating in the direction that is already saturated.
  if (!(atHi && err > 0.0f) && !(atLo && err < 0.0f)) {
    w.integral = constrain(w.integral + VEL_KI * err * dt, -255.0f, 255.0f);
  }

  // Encoder sanity: turning the wrong way, or driven hard and not turning.
  bool wrongWay = (w.measured * w.target < 0.0f) &&
                  (fabsf(w.measured) > ENC_FAULT_MIN_MPS);
  bool noMotion = (fabsf(out) >= (float)ENC_FAULT_PWM) &&
                  (fabsf(w.measured) < ENC_FAULT_MIN_MPS);
  if (wrongWay || noMotion) {
    if (w.badSinceMs == 0) {
      w.badSinceMs = now ? now : 1;
    } else if (now - w.badSinceMs > ENC_FAULT_MS) {
      encoderFault = true;
      DBG.printf("[vel] ENCODER FAULT (%s) -> open-loop until RESET_FAULT\n",
                 wrongWay ? "counts opposite to the motor" : "no counts / stalled");
      return ff;
    }
  } else {
    w.badSinceMs = 0;
  }

  return (int)out;
}

// Runs every loop(); steps both wheel controllers at VEL_PERIOD_MS.
void updateVelocityControl() {
  uint32_t now = millis();
  if (now - lastVelMs < VEL_PERIOD_MS) return;
  float dt = (float)(now - lastVelMs) * 0.001f;
  lastVelMs = now;

  long t1, t2;
  readEncoderCounts(t1, t2);

  // Always step, so the measured speeds stay current while the fallback
  // maneuver or a stop owns the motors.
  int pwmL = wheelControlStep(wheelL, t1, dt, now);
  int pwmR = wheelControlStep(wheelR, t2, dt, now);
  if (!velControlActive) return;

  setMotor(1, pwmL);
  setMotor(2, pwmR);
}

// Named helpers used by the fallback maneuver
void moveForward() { setMotor(1,  MOTOR_SPEED); setMotor(2,  MOTOR_SPEED); }
void turnRight()   { setMotor(1, -MOTOR_SPEED); setMotor(2,  MOTOR_SPEED); }
void turnLeft()    { setMotor(1,  MOTOR_SPEED); setMotor(2, -MOTOR_SPEED); }


// ============================================================
// ENCODERS - quadrature x4 counting
// ============================================================

void IRAM_ATTR motor1ISR() {
  bool a = digitalRead(M1_ENC_A);
  bool b = digitalRead(M1_ENC_B);
  if (a == b) motor1_encoder_count += M1_ENC_INVERT ? -1 : 1;
  else        motor1_encoder_count += M1_ENC_INVERT ?  1 : -1;
}

void IRAM_ATTR motor2ISR() {
  bool a = digitalRead(M2_ENC_A);
  bool b = digitalRead(M2_ENC_B);
  if (a == b) motor2_encoder_count += M2_ENC_INVERT ? -1 : 1;
  else        motor2_encoder_count += M2_ENC_INVERT ?  1 : -1;
}

void readEncoderCounts(long& t1, long& t2) {
  noInterrupts();
  t1 = motor1_encoder_count;
  t2 = motor2_encoder_count;
  interrupts();
}


// ============================================================
// FRAME TRANSMIT HELPERS
// ============================================================

void sendFrame(uint8_t msgId, const uint8_t* payload, uint8_t len) {
  uint8_t buf[ff::MAX_PAYLOAD + 6];
  uint16_t n = ff::encodeFrame(buf, msgId, payload, len);
  PiLink.write(buf, n);
}

void sendAck(uint8_t ackedId) {
  uint8_t p[1];
  ff::put_u8(p, ackedId);
  sendFrame(ff::MSG_ACK, p, 1);
}

void sendHeartbeat() {
  uint8_t p[2];
  ff::put_u16(p, ++hbSeq);
  sendFrame(ff::MSG_HB_ESP, p, 2);
}

void sendWheelOdom(long ticks1, long ticks2, uint32_t dtUs) {
  uint8_t p[12];
  ff::put_i32(p,     (int32_t)ticks1);
  ff::put_i32(p + 4, (int32_t)ticks2);
  ff::put_u32(p + 8, dtUs);
  sendFrame(ff::MSG_WHEEL_ODOM, p, 12);
}

void sendStatus() {
  uint8_t flags = 0;
  if (!linkFault && (millis() - lastPiFrameMs <= PI_TIMEOUT_MS)) flags |= ff::FLAG_LINK_OK;
  if (estop)                              flags |= ff::FLAG_ESTOP;
  if (motorCmdA > 0 || motorCmdB > 0)     flags |= ff::FLAG_MOVING;
  if (!MOTION_OWNER_IS_PI)                flags |= ff::FLAG_FALLBACK;
  if (encoderFault)                       flags |= ff::FLAG_ENC_FAULT;

  uint8_t p[4];
  ff::put_u16(p,     0);          // vbat_mV: no battery ADC yet
  ff::put_u8 (p + 2, flags);
  ff::put_u8 (p + 3, MOTION_OWNER_IS_PI ? ff::MODE_PI : ff::MODE_FALLBACK);
  sendFrame(ff::MSG_STATUS, p, 4);
}

void sendBeaconEvent(const struct_message& m, uint8_t rssi, const uint8_t* mac) {
  uint8_t p[13];
  ff::put_u32(p,     (uint32_t)m.messageNumber);
  ff::put_u8 (p + 4, m.fireDetected  ? 1 : 0);
  ff::put_u8 (p + 5, m.smokeDetected ? 1 : 0);
  ff::put_u8 (p + 6, rssi);       // signal strength magnitude in dBm (e.g. 65 for -65 dBm)
  memcpy(p + 7, mac, 6);
  sendFrame(ff::MSG_BEACON_EVENT, p, 13);
}


// ============================================================
// WATCHDOG
// ============================================================

void notePiFrame() {
  lastPiFrameMs = millis();
  if (linkFault) {
    linkFault = false;
    DBG.printf("[link] Pi frames resumed\n");
  }
}

void updateWatchdog() {
  if (!MOTION_OWNER_IS_PI) return;

  if (estop) {
    stopMotors();
    return;
  }

  if (millis() - lastPiFrameMs > PI_TIMEOUT_MS) {
    if (!linkFault) {
      linkFault = true;
      stopMotors();
      DBG.printf("[link] watchdog timeout -> MOTORS STOPPED\n");
    }
    return;
  }

  if (linkFault) stopMotors();   // stay stopped until a new SET_TWIST
}


// ============================================================
// COMMAND HANDLING (Pi -> ESP32)
// ============================================================

void applyTwist(float lin, float ang) {
  if (!MOTION_OWNER_IS_PI) return;
  if (estop || linkFault)  return;

  float vL = lin - ang * (TRACK_WIDTH_M / 2.0f);
  float vR = lin + ang * (TRACK_WIDTH_M / 2.0f);
  setWheelTargets(vL, vR);
}

void handleFrame(const ff::Frame& f) {
  switch (f.msgId) {
    case ff::MSG_SET_TWIST:
      if (f.len == 8) {
        applyTwist(ff::get_f32(f.payload), ff::get_f32(f.payload + 4));
        notePiFrame();
      }
      sendAck(f.msgId);
      break;

    case ff::MSG_ESTOP:
      estop = true;
      stopMotors();
      notePiFrame();
      DBG.printf("[cmd] ESTOP latched\n");
      sendAck(f.msgId);
      break;

    case ff::MSG_RESET_FAULT:
      estop        = false;
      linkFault    = false;
      encoderFault = false;
      wheelL.badSinceMs = wheelR.badSinceMs = 0;
      notePiFrame();
      DBG.printf("[cmd] faults cleared\n");
      sendAck(f.msgId);
      break;

    case ff::MSG_HEARTBEAT:
      notePiFrame();
      break;

    default:
      break;
  }
}


// ============================================================
// FALLBACK MANEUVER (only when MOTION_OWNER_IS_PI == 0)
//
// Same behaviour as the legacy firmware, but driven by a
// millis() state machine so the UART is serviced continuously.
// ============================================================

// (enum FbState is declared in the STATE section, above the first function)

FbState  fbState      = FB_IDLE;
uint32_t fbStateStart = 0;
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
void loop() {
  // ---- 1. Service the Pi UART (highest priority) ----------
  while (PiLink.available()) {
    if (parser.feed((uint8_t)PiLink.read(), frame)) {
      handleFrame(frame);
    }
  }

  // ---- 2. Safety -----------------------------------------
  updateWatchdog();

  // ---- 3. Fallback maneuver ------------------------------
  fallbackUpdate();

  // ---- 3b. Wheel speed loop (after safety, so a stop wins) -
  updateVelocityControl();

  // ---- 4. Beacon pairing ---------------------------------
  if (pairReplyPending) {
    pairReplyPending = false;
    sendPairReply();
  }

  // ---- 5. Periodic telemetry -----------------------------
  uint32_t now = millis();

  if (now - lastOdomMs >= ODOM_PERIOD_MS) {
    uint32_t dtMs = now - lastOdomMs;
    lastOdomMs = now;
    long t1, t2;
    readEncoderCounts(t1, t2);
    sendWheelOdom(t1, t2, dtMs * 1000UL);
  }

  if (now - lastStatusMs >= STATUS_PERIOD_MS) {
    lastStatusMs = now;
    sendStatus();
  }

  if (now - lastHbMs >= HB_PERIOD_MS) {
    lastHbMs = now;
    sendHeartbeat();
  }

  // ---- 6. Yield ------------------------------------------
  delay(1);
}

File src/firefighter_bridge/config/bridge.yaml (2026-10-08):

# Parameters for firefighter_bridge/bridge_node.
#
# Adjust `port`, wheel geometry and tick counts to the real robot. `ticks_per_rev`
# is the ENCODER count per wheel revolution - the firmware counts quadrature x4,
# so a 360 CPR encoder gives 1440.
firefighter_bridge:
  ros__parameters:
    # ---- UART link -------------------------------------------------
    port: /dev/ttyAMA0        # PL011 on GPIO14/15 (see docs/runbook.md)
    baud: 115200

    # ---- /cmd_vel -> SET_TWIST -------------------------------------
    cmd_vel_topic: /cmd_vel
    cmd_rate_hz: 20.0         # how often SET_TWIST is streamed
    cmd_timeout_s: 0.5        # stale /cmd_vel -> command zero (must be < ESP watchdog)

    # ---- WHEEL_ODOM -> odometry ------------------------------------
    odom_topic: /wheel_odom   # NOT /odom: rf2o owns odom->base_link (see README)
    publish_tf: false         # leave false while rf2o broadcasts odom->base_link
    odom_frame: odom
    base_frame: base_link
    wheel_radius_m: 0.0325
    ticks_per_rev: 1440       # 360 CPR x4 quadrature
    track_width_m: 0.20
    vx_variance: 0.01         # (m/s)^2 on /wheel_odom twist; raise if geometry is unverified
    vyaw_variance: 0.05       # (rad/s)^2; wheel slip makes yaw rate the weaker of the two

    # ---- Events / status -------------------------------------------
    beacon_topic: /beacon_event
    battery_topic: /battery
    diagnostics_topic: /diagnostics

    # ---- Health ----------------------------------------------------
    heartbeat_hz: 2.0         # HEARTBEAT frames sent to the ESP32
    esp_timeout_s: 2.0        # warn if the ESP32 goes quiet this long

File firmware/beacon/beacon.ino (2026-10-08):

// ============================================================
// FIREFIGHTING ROBOT - WIRELESS FIRE BEACON (SENDER)
// ESP32 Arduino Core 2.0.x
//
// ROLE
//   * Senses fire (HL-01 IR flame sensor) and smoke (MQ-2)
//   * Periodically broadcasts/unicasts alert packets to the
//     mobility controller ESP32 via ESP-NOW
//
// !! NON-BLOCKING: the control and transmission path uses
//    millis() only. No blocking delay() calls in loop().
// ============================================================

#include <WiFi.h>
#include <esp_now.h>

// ============================================================
// RECEIVER DISCOVERY (Robot Mobility ESP32)
//
// The receiver MAC is not hardcoded. The beacon broadcasts a
// PAIR_REQUEST until the mobility ESP32 answers with a PAIR_REPLY,
// then takes the receiver MAC from the source address of that reply.
// If the receiver stops acknowledging packets the beacon forgets it
// and starts discovering again.
// ============================================================
const uint8_t BROADCAST_MAC[6] = {0xFF, 0xFF, 0xFF, 0xFF, 0xFF, 0xFF};

// Pairing message (MUST MATCH robot_mobility.ino EXACTLY).
// Its size differs from struct_message, so the two never get confused.
const uint32_t PAIR_MAGIC   = 0x46465052;   // "FFPR"
const uint8_t  PAIR_REQUEST = 1;            // beacon   -> broadcast
const uint8_t  PAIR_REPLY   = 2;            // mobility -> broadcast

typedef struct __attribute__((packed)) pair_message {
  uint32_t magic;
  uint8_t  type;
} pair_message;

const uint32_t DISCOVERY_PERIOD_MS = 500;   // PAIR_REQUEST interval while searching
const int      MAX_SEND_FAILURES   = 5;     // consecutive failed packets -> rediscover

uint8_t receiverMAC[6] = {0};
bool    receiverKnown  = false;
uint32_t lastDiscoveryMs = 0;

// Written by the ESP-NOW callbacks (Wi-Fi task), consumed in loop()
volatile bool pairReplyPending = false;
uint8_t       pairReplyMAC[6]  = {0};
volatile int  sendFailCount    = 0;


// ============================================================
// MESSAGE STRUCTURE (MUST MATCH RECEIVER EXACTLY)
// ============================================================
typedef struct struct_message {
  int  messageNumber;
  bool fireDetected;
  bool smokeDetected;
} struct_message;

struct_message outgoingData;


// ============================================================
// TIMING (all non-blocking, millis() based)
// ============================================================
const uint32_t BEACON_PERIOD_MS = 2000;   // transmission period (2 seconds)
uint32_t lastSendMs = 0;


// ============================================================
// SENSOR / LED PINS
// ============================================================
const int FLAME_PIN = 18;   // HL-01 IR flame sensor, D0
const int SMOKE_PIN = 19;   // MQ-2 smoke sensor, D0
const int LED_PIN   = 2;    // alarm LED

// Both modules use an LM393 comparator whose D0 output goes LOW
// when the threshold (set by the on-board trimmer) is exceeded.
// Flip these if a module reads the other way round.
const int FLAME_ACTIVE_LEVEL = LOW;
const int SMOKE_ACTIVE_LEVEL = LOW;


// ============================================================
// STATE
// ============================================================
int messageCounter = 0;

// Detections latched since the last packet, so an event shorter
// than BEACON_PERIOD_MS is still reported.
bool fireLatched  = false;
bool smokeLatched = false;


// ============================================================
// SEND CALLBACK
// ============================================================
// ESP-IDF 5.5 (Arduino core 3.3.x) changed the first argument of the
// send callback from the peer MAC to a wifi_tx_info_t.
#if defined(ESP_IDF_VERSION) && (ESP_IDF_VERSION >= ESP_IDF_VERSION_VAL(5, 5, 0))
void OnDataSent(const wifi_tx_info_t *tx_info, esp_now_send_status_t status) {
#else
void OnDataSent(const uint8_t *mac_addr, esp_now_send_status_t status) {
#endif
  if (!receiverKnown) return;   // discovery broadcasts are never acknowledged

  Serial.print("Delivery Status: ");
  if (status == ESP_NOW_SEND_SUCCESS) {
    Serial.println("SUCCESS");
    sendFailCount = 0;
  } else {
    Serial.println("FAILED");
    sendFailCount = sendFailCount + 1;
  }
}


// ============================================================
// RECEIVE CALLBACK (pairing replies only)
// ============================================================
void handlePairReply(const uint8_t *mac, const uint8_t *data, int len) {
  if (receiverKnown || pairReplyPending) return;
  if (!mac || len != (int)sizeof(pair_message)) return;

  pair_message msg;
  memcpy(&msg, data, sizeof(msg));
  if (msg.magic != PAIR_MAGIC || msg.type != PAIR_REPLY) return;

  memcpy(pairReplyMAC, mac, 6);
  pairReplyPending = true;
}

#if defined(ESP_IDF_VERSION) && (ESP_IDF_VERSION >= ESP_IDF_VERSION_VAL(5, 0, 0))
void OnDataRecv(const esp_now_recv_info_t *info, const uint8_t *data, int len) {
  handlePairReply(info ? info->src_addr : nullptr, data, len);
}
#else
void OnDataRecv(const uint8_t *mac_addr, const uint8_t *data, int len) {
  handlePairReply(mac_addr, data, len);
}
#endif


// ============================================================
// RECEIVER DISCOVERY
// ============================================================
void sendPairRequest() {
  pair_message msg = { PAIR_MAGIC, PAIR_REQUEST };
  esp_now_send(BROADCAST_MAC, (const uint8_t *)&msg, sizeof(msg));
  Serial.println("Searching for mobility ESP32...");
}

void forgetReceiver() {
  esp_now_del_peer(receiverMAC);
  receiverKnown = false;
  sendFailCount = 0;
  Serial.println("Receiver lost. Restarting discovery.");
}

// Runs in loop(): finish a pending pairing, drop a dead receiver,
// and keep broadcasting PAIR_REQUEST while no receiver is known.
void updateDiscovery(uint32_t now) {
  if (receiverKnown && sendFailCount >= MAX_SEND_FAILURES) {
    forgetReceiver();
  }

  if (pairReplyPending) {
    esp_now_peer_info_t peerInfo = {};
    memcpy(peerInfo.peer_addr, pairReplyMAC, 6);
    peerInfo.channel = 0;
    peerInfo.encrypt = false;

    if (esp_now_add_peer(&peerInfo) == ESP_OK) {
      memcpy(receiverMAC, pairReplyMAC, 6);
      sendFailCount = 0;
      receiverKnown = true;
      Serial.printf("Receiver found: %02X:%02X:%02X:%02X:%02X:%02X\n",
                    receiverMAC[0], receiverMAC[1], receiverMAC[2],
                    receiverMAC[3], receiverMAC[4], receiverMAC[5]);
    } else {
      Serial.println("ERROR: Failed to add receiver!");
    }
    pairReplyPending = false;
  }

  if (!receiverKnown && now - lastDiscoveryMs >= DISCOVERY_PERIOD_MS) {
    lastDiscoveryMs = now;
    sendPairRequest();
  }
}
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

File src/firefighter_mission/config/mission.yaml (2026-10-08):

# Parameters for firefighter_mission/mission_node.
firefighter_mission:
  ros__parameters:
    # ---- topics -----------------------------------------------------
    beacon_topic: /beacon_event        # in:  from firefighter_bridge
    flame_topic: /flame_event          # in:  from firefighter_perception (later)
    goal_viz_topic: "~/goal_pose"      # out: the goal, published for display only
    use_nav2: true                     # false = publish the goal, wait for a manual event
    nav_action: navigate_to_pose       # Nav2 NavigateToPose action server name
    cmd_vel_topic: /cmd_vel            # out: search spin, approach + stop (feeds the bridge)
    suppress_topic: "~/suppress"       # out: Bool, extinguisher on/off
    state_topic: "~/state"             # out: String, current FSM state
    event_topic: "~/event"             # in:  String, manual event injection
    diagnostics_topic: /diagnostics    # out

    # ---- goal selection --------------------------------------------
    goal_frame: map
    goal_x: 0.0                        # fallback goal when no beacon map entry
    goal_y: 0.0
    goal_yaw: 0.0
    beacon_goals_file: ""              # YAML: "aa:bb:cc:dd:ee:ff: {x: 3.0, y: 1.5, yaw: 0.0}"

    # ---- behaviour --------------------------------------------------
    search_spin_rate: 0.5              # rad/s sweep while SEARCHING
    approach_speed: 0.15               # m/s creep toward the flame while APPROACHING
    approach_turn_gain: 1.5            # rad/s of turn per rad of flame bearing
    approach_max_turn_rate: 0.8        # rad/s cap on that turn
    approach_align_rad: 0.25           # only drive forward once the bearing is inside this
    flame_stale_s: 1.0                 # hold still if the flame was last seen longer ago
    flame_lost_frames: 3               # consecutive FLAME_LOST frames before acting on it
    tick_rate_hz: 10.0
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

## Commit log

2026-10-07 feat(bridge): add Pi↔ESP32 UART bridge with shared protocol and interfaces
    Wire the mobility ESP32 into the ROS 2 graph so `/cmd_vel` reaches the motors
    and wheel odometry, beacon alerts and status come back to the Pi.
    - firefighter_bridge (ament_python): framed UART node with protocol codec,
    serial link, launch file and `bridge.yaml` parameters. Publishes `/wheel_odom`,
    `/beacon_event`, `/battery`, `/diagnostics`; provides `~/estop` and
    `~/clear_fault` services; streams `SET_TWIST` to keep the ESP32 watchdog fed.
    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
2026-10-07 feat(beacon): add wireless fire beacon sender implementation with ESP-NOW
2026-10-07 feat (mission): Add firefighter mission behavior state machine and related components
    - Implement mission behavior state machine with states: IDLE, CONFIRMING, NAVIGATING, SEARCHING, APPROACHING, SUPPRESSING, VERIFYING, COMPLETE, ABORTED.
    - Create FlameEvent message for flame detection and suppression states.
    - Develop mission_node to handle ROS interactions and state transitions.
    - Add configuration file for mission parameters.
    - Implement unit tests for the mission FSM to ensure correct behavior.
    - Create launch file for easy deployment of the mission node.
    - Update package.xml and setup.py for new dependencies and configurations.
    [mission.yaml]
2026-10-07 feat(viewer): add browser-based 2D/3D LiDAR viewer and related documentation
2026-10-07 feat(viewer): add initial SVG for LiDAR viewer
2026-10-07 feat(thermal camera): Add support for Melexis MLX90641 thermal camera
    - Introduced new documentation for the Melexis MLX90641 thermal camera, detailing wiring, usage, and integration plans.
    - Added C++ reader for capturing thermal frames from the MLX90641 and outputting them as CSV.
    - Implemented Python script to capture frames and render them as PNG images.
    - Removed dependency on adafruit-circuitpython-mlx90640, as the MLX90641 is not compatible.
    - Added build script for the C++ reader, ensuring the vendor library is cloned and compiled.
    - Included sample thermal images in the documentation.
    [mlx90641_frames.cpp]
2026-10-08 feat(tools): add operations dashboard and motor bench test utility
    Replace the standalone LiDAR web viewer with a unified operations dashboard
    and introduce a drive-train bench testing script.
    - Replace `scripts/lidar_web_viewer.py` with `scripts/robot_dashboard.py`
    (and rename `lidar-viewer.svg` to `robot-dashboard.svg`), providing a
    browser-based dashboard covering 2D/3D LiDAR views, beacon alerts,
    ESP32 link/e-stop status, mission FSM state, odometry, and topic rates.
    - Add `scripts/motor_test.py` for scripted and interactive keyboard-driven
    motor bring-up via `/cmd_vel` with `/wheel_odom` feedback and safety stops.
    - Update `README.md` and `docs/runbook.md` with instructions and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
2026-10-08 fix(beacon, robot_mobility): update callback and variable names for ESP-IDF compatibility
    [beacon.ino, robot_mobility.ino]
2026-10-08 feat(beacon): enhance sensor handling and update detection logic
2026-10-08 feat(bringup,perception,nav): add full-stack bringup, thermal perception, and Nav2 integration
    Wire the robot's sensing, autonomy and mission layers into one launchable
    stack, and give the mission FSM a real navigation backend.
    New packages:
    - `firefighter_bringup`: single `bringup.launch.py` starting sllidar, rf2o,
    the robot_localization EKF, the ESP32 bridge, thermal perception, SLAM
    Toolbox, Nav2, the mission FSM and RViz. Documents REP-105 TF ownership
    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
2026-10-08 feat(robot_mobility): implement closed-loop wheel speed control and update PWM configuration
2026-10-08 feat(encoder): add encoder fault handling and reporting to the system
2026-10-08 feat(dashboard): add status tiles, orient LiDAR forward-up, and refine UI layout
2026-10-08 feat(dashboard): add live thermal camera feed and SLAM map view
    - Add support for `/thermal/image` live feed rendered as an interactive 16x12 heatmap with peak temperature highlighting and pixel hover tooltips.
    - Add an interactive SLAM `/map` view mode alongside 2D/3D LiDAR views, displaying the occupancy grid, robot pose via TF (`map -> base_link`), trail, live scan points, mission goal, and flame bearing.
    - Implement conditional fetching so thermal and map binary/JSON streams are only polled when actively visible on screen.
    - Add CLI arguments `--thermal-topic`, `--map-topic`, and `--base-frame` to configure or disable either feed.
    - Update `README.md` and `docs/runbook.md` with usage ins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
2026-10-09 feat: add firefighter model builder, blend file, render script, and preview images
    [firefighter.blend]
2026-10-09 feat: add firefighter_description package and Gazebo simulation stack
    - Add firefighter_description package with URDF/XACRO model, STL visual meshes, and Gazebo plugins
    - Add model/export_firefighter_description.py to automate LinkForge export from Blender to package:// URIs
    - Configure joint effort and velocity limits in model/build_firefighter_model.py
    - Add firefighter_bringup/launch/sim.launch.py for Gazebo Harmonic with ros_gz bridges
    - Update bringup.launch.py to use robot_state_publisher from firefighter_description instead of static TF publishers
    - Add hardware launch argument to toggle real hardware nodes vs simulation
    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
    [base_link_visual_0.stl, base_link_visual_1.stl, base_link_visual_2.stl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]
2026-10-09 feat(sim): add simulated thermal camera support for Gazebo
    - Add MLX90641 ThermalSensor plugin to firefighter.gazebo.xacro publishing 16-bit images on /thermal/raw
    - Add sim_thermal_frames node in firefighter_perception to convert /thermal/raw into MLX90641 CSV format on stdout
    - Update sim.launch.py to bridge /thermal/raw and route sim_thermal_frames to the perception node
    - Enable thermal perception in bringup.launch.py when hardware:=false
    - Update setup.md and bringup README with simulated thermal detection and troubleshooting details
    [firefighter.gazebo.xacro]
2026-10-09 feat(sim): optimize simulation performance, add headless mode, and tune RViz
    - Increase Gazebo physics max_step_size to 4 ms in firehouse.sdf to maintain 1.0 real-time factor
    - Add gui launch argument to sim.launch.py to support headless server mode (gz sim -s)
    - Enable RobotModel display by default in firefighter.rviz
    - Update RViz ThermalCamera display range (10-350 °C) for fire visualization
    - Document gui:=false launch option and real-time factor troubleshooting in setup.md
    [firehouse.sdf]
2026-10-19 feat(model): add 3D scanner PoC documentation, models, and renders
    Reuses the dead RPLIDAR A1 turntable and motor base to create an off-axis
    rotating 3D scanner rig with a camera and single-point ToF distance sensor.
    - Add comprehensive PoC design document (`docs/3d-scanner-poc.md`) covering
    off-axis stereo rationale, baseline error analysis, and ToF comparison
    - Add `model/build_scanner_model.py` to generate Blender models for both
    VL53L1X and TFmini-S sensor variants via LinkForge
    - Generate Blender models for both scanner variants (`.blend`)
    - Update `model/render_firefighter_model.py` to output renders to subdirectories
    - Add preview renders (front right, rear left, side, top) for b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
